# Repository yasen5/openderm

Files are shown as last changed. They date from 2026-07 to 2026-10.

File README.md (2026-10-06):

# OpenDerm

[OpenDerm](https://openderm.github.io/) is an open-source robotic imaging system for creating high-resolution, reproducible 3D maps of the skin that can be compared over time to detect early signs of skin cancer.

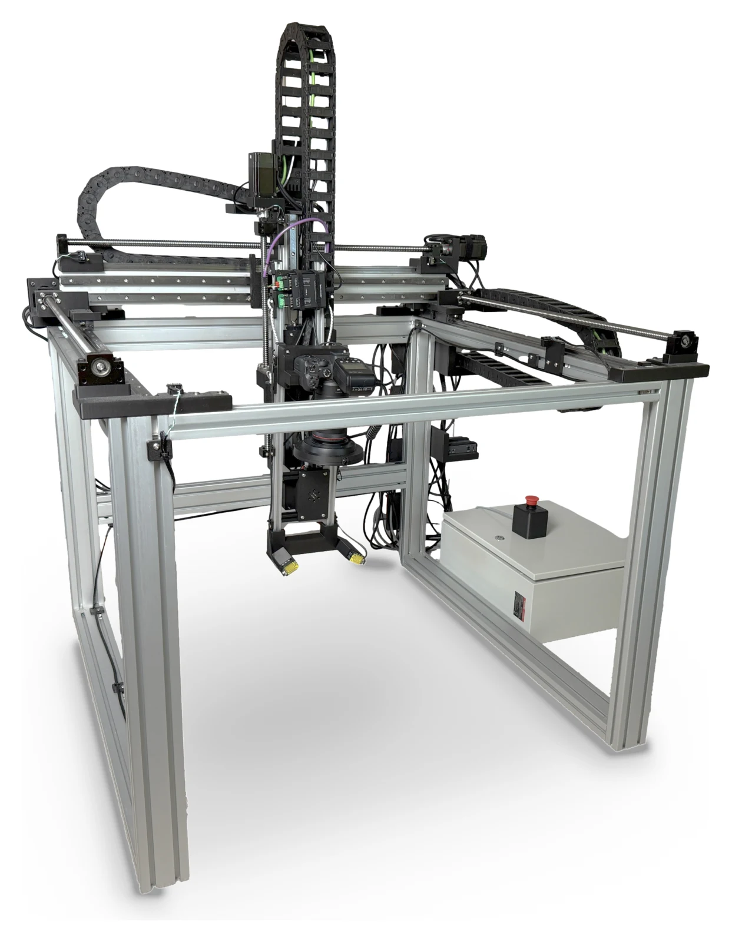
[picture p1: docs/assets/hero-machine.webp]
The OpenDerm four-DOF robotic skin-imaging system


## System architecture

The system uses three computers:

| Computer | Connected hardware | OpenDerm role |
| --- | --- | --- |
| Raspberry Pi #1 (`openderm-gantry.local`) | Octopus Pro/Klipper and the Y/Z Pico | X-axis gantry API and Pico TCP bridge |
| Raspberry Pi #2 | CAN-controlled RX-axis motor, Canon EOS R7, ADS1115, sensor GPIO | Homing, standoff regulation, and scan capture |
| Workstation | | 3D reconstruction, longitudinal comparison |

Raspberry Pi #1 controls the X-axis via Klipper. The Raspberry Pi Pico controls the Y and Z axes; Raspberry Pi #2 controls the RX joint, the camera, and the distance sensors.

## Documentation

### Build and configure

- [Project website](https://openderm.github.io/) — project overview, hardware design, CAD, bill of materials, wiring, and assembly instructions.
- [Raspberry Pi and Octopus Pro setup](docs/fresh-start-pi-octopus-pro.md) — configure Raspberry Pi #1, Klipper, Moonraker, and the X-axis controller.

### Operate and capture

- [Motion control](docs/motion.md) — start the motion services and control the X, Y, Z, and RX axes.
- [Distance sensors and RX limit switches](docs/sensors.md) — sensor wiring, readings, and limit-switch commands.
- [Camera capture](docs/camera.md) — configure Canon EDSDK and capture photographs.
- [Capture and processing procedure](docs/scanning-procedure.md) — preflight, calibration, scanning, reconstruction, and scan comparison.

### Process and compare

- [Skin reconstruction and registration](docs/skin-registration.md) — reconstruction method, longitudinal comparison, uncertainty, and limitations.
- [Simulated capture from freehand photos](docs/sim-capture.md) — build a processing-ready scan with COLMAP when the gantry is unavailable.

### Technical references

- [Self-collision guard](docs/collision_guard.md) — collision-envelope generation, runtime enforcement, and safety behavior.
- [Calibration and collision scripts](docs/calibration-and-collision.md) — RX-pivot calibration, floor calibration, and collision-envelope tools.

## Install

OpenDerm requires Python 3.11 or newer. Clone OpenDerm on both Raspberry Pis and install it into a virtual environment:

```bash
python3.11 -m venv .venv
source .venv/bin/activate
python -m pip install --upgrade pip
python -m pip install -e ".[hardware]"
```

Copy [config/openderm.env.example](config/openderm.env.example) to an untracked local file on both Pis and edit the hostnames or IP addresses. Generate one shared control token, put the same value in both files, and never commit it:

```bash
python -c 'import secrets; print(secrets.token_urlsafe(32))'
```

Load the environment in each shell:

```bash
set -a
source /path/to/openderm.env
set +a
```

If `openderm-gantry.local` does not resolve on Raspberry Pi #2 or an operator workstation, use Raspberry Pi #1's reserved LAN address instead (e.g. 192.168.1.188).

## Start

On Raspberry Pi #1, start the X-axis service and Pico bridge in separate terminals:

```bash
openderm-gantry-server --host 0.0.0.0 --port 8090
openderm-pico-bridge --host 0.0.0.0 --port 8095
```

Non-loopback motion services refuse to start without `OPENDERM_CONTROL_TOKEN`. HTTP clients and the Pico socket client read the token from the environment automatically. Keep ports 8090 and 8095 on a private, firewalled control network; the token does not replace network segmentation or a physical emergency stop.

On Raspberry Pi #2, start the RX-axis service:

```bash
openderm-rx-axis-server --axis rx --host 127.0.0.1 --port 8091
```

## Home and move the robot

Use the `home` and `move-to` commands for every axis:

```bash
openderm --axis x home
openderm --axis x move-to 250 --feed 900

openderm --axis y home
openderm --axis y move-to 175
openderm --axis z home
openderm --axis z move-to 200

openderm --axis rx home
openderm --axis rx move-to 0.95 --speed 0.2
```

The configured linear travel limits are X: 0–800 mm, Y: 0–665 mm, and Z: 0–392 mm. Verify direction, limit switches, and stopping behavior one axis at a time before running a coordinated workflow.

## Regulate standoff

On Raspberry Pi #2, regulate the camera head to the configured 110 mm working distance above the subject:

```bash
openderm-regulate --debug
```

`PICO_PORT` defaults to a TCP bridge derived from `GANTRY_SERVER_URL`. For example, setting `GANTRY_SERVER_URL=http://192.168.1.188:8090` automatically selects `socket://192.168.1.188:8095` unless `PICO_PORT` is set explicitly. Run `openderm-regulate --help` to inspect or adjust the regulation parameters.

## Capture scans

`openderm-scan` follows the subject contour:

```bash
openderm-scan captures/subject-001-site-001 --debug
```

Inspect the resolved capture parameters without moving hardware:

```bash
openderm-scan captures/subject-001-site-001 --show-config
```

Run `openderm-scan captures/subject-001-site-001 --advanced-help` to list the tuning options. Follow the preflight, subject-positioning, focus, overlap, and edge-recovery procedure in [docs/scanning-procedure.md](docs/scanning-procedure.md) before a human scan.

## Reconstruct and compare scans

Install the vision dependencies on a workstation:

```bash
python3.11 -m venv .venv
source .venv/bin/activate
python -m pip install -e ".[vision]"
```

Calibrate the intrinsics of your camera independently with the exact lens, manual-focus setting, and full-resolution image dimensions used for capture. OpenDerm does not provide a camera-calibration utility. The reference camera's full-resolution focal length, `39237 px`, is the default; supply your calibrated focal length with `--fx-full` when it differs:

```bash
openderm-process captures/subject-001-site-001 --fx-full <focal-length-px>
```

`openderm-process` fits the rig model for the current scan, builds the canonical reconstruction, and runs both artifact checks:

```bash
openderm-process captures/subject-001-site-001
```

Use `--quality full` for the sharpest 78 px/mm texture after the preview passes artifact checks.

Compare two canonical scans of the same anatomical site:

```bash
openderm-compare subject-001-site-001 subject-001-site-002 --captures captures
```

Processing outputs include `texture.jpg`, `surface_mesh.obj`, `viewer.html`, `placements3d.json`, `report.txt`, artifact-check crops, and a longitudinal change report. See [docs/skin-registration.md](docs/skin-registration.md) for the reconstruction and uncertainty model.

## Repository layout

- `src/capture/` — hardware control and capture workflows.
- `src/processing/` — 3D registration, artifact detection, and scan comparison.
- `src/sim_capture/` — COLMAP-based stand-in for `src/capture` that builds a scan from freehand photos.
- `src/pico/` — MicroPython Y/Z motion firmware.
- `src/tests/` — hardware-free unit and simulation tests.
- `src/scripts/calibration/` — RX-pivot and floor calibration tools.
- `src/scripts/collision/` — CAD-derived collision-envelope tools.
- `config/` — environment templates, Klipper configuration, CAD models, calibration, and collision tables.
- `third_party/` — vendored Three.js libraries and the Pico compatibility launcher.
- `docs/` — setup, operation, reconstruction, and safety documentation.

Non-code test fixtures belong in `test-assets/` when needed; generated example
outputs are not tracked. Documentation, licenses, and files required at fixed
locations by build tools or GitHub remain outside these directories.

## Verify the installation

```bash
python -m pip install -e ".[hardware,vision]"
python -m pip install pytest
python -m pytest
```

## Safety
> **Caution:** OpenDerm is research software, not a medical device, and does not diagnose melanoma or any other condition. Operating the robot can cause impact, pinch, electrical, and laser hazards; validate limits and emergency stops without a person in the workspace before human imaging.

## License

OpenDerm is available under the [MIT License](LICENSE).

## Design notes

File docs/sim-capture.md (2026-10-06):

# Simulated capture from freehand photos (sim-capture)

`sim-capture` replaces `src/capture` when the gantry is unavailable. It takes a
folder of photographs taken by hand, lets COLMAP estimate where every photo was
taken and the shape of the surface, and writes a capture folder that
`src/processing` reconstructs the same way it reconstructs a gantry scan.

It does not touch `src/capture`, and nothing in `src/capture` is needed to run it.

## What it is and is not

- **Poses are estimated, not measured.** The gantry reports camera position to
  about a millimetre from its encoders. Here the poses come from the images, so
  they are exactly as good as the images allow. Processing still refines them
  with its own bundle adjustment.
- **Scale is not observable from images.** You tell sim-capture the approximate
  mean camera-to-surface distance with `--standoff-mm`, and everything in
  millimetres follows from that number. A 5% error in the standoff is a 5% error
  in every length, including lesion sizes in `openderm-compare`. Do not use
  sim-capture output for clinical measurement.
- **One camera, one zoom.** All images must share a size and focal length. The
  focal length and radial distortion are estimated by COLMAP, not read from a
  calibration.
- **One-sided capture.** Processing models the subject as a heightfield
  `z = f(x, y)` seen from above. Photos should look at the same side of the
  subject with neighbouring views overlapping by about 60%. A full orbit around
  an arm is reported as a warning and will not reconstruct well.
- **No breathing-group handling.** The gantry path registers scan rows
  separately to cancel breathing; freehand captures are registered as one rigid
  group.

## Install

```bash
python -m pip install -e ".[vision,sim]"
```

`pycolmap` provides COLMAP. The CPU build is sufficient; COLMAP's own
`colmap` command is not required.

## Run

```bash
openderm-sim-capture photos/ --out captures/arm-sim-001 --standoff-mm 250
openderm-sim-capture photos/ --out captures/arm-sim-001 --standoff-mm 250 --force --process
```

The first command stops after writing the capture folder and prints the
processing command. `--process` runs it. COLMAP and processing memory grows with
the number and resolution of the images (about 1.5 GB for 24 images at 640x480
during COLMAP in testing), so cap or monitor memory on large sets. COLMAP's SIFT needs about 1 GB per thread at
1440x2560, so `--threads` defaults to 4 (16 threads ran out of memory at 10 GB).

Registration statistics, warnings and the scale factor are in
`captures/arm-sim-001/sim/report.json`. Read it before trusting the result:

| Field | What to look for |
|---|---|
| `images_registered` / `images_unregistered` | Most images should register. Below 50% sim-capture refuses to continue (`--min-registered-frac`). |
| `mean_reprojection_error_px` | Well under 1 px for a good run. |
| `other_models_sizes` | Non-empty means COLMAP found disconnected groups of photos. Only the largest is used. |
| `warnings` | Captures that wrap around the subject, strongly three-dimensional subjects, or very oblique views. |

## Output

```
captures/arm-sim-001/
  <image>.jpg, <image>.json   one pair per registered image (processing's input)
  sim/poses.json              COLMAP poses + intrinsics, read by --poses-from
  sim/report.json             statistics, scale, warnings
  sim/sparse.ply              sparse surface in millimetres
  registration3d/             processing outputs (after --process)
```

The `.json` sidecars follow the gantry schema so the loader accepts them. Their
position fields hold the camera centre and the rotation and distance-sensor fields
hold the surface distance; processing ignores them for pose when `--poses-from`
is given. Every sidecar carries `"sim": true`.

`sim-capture` refuses to write into a folder containing JSON it did not create,
so it cannot mix with a real scan. `--force` replaces only an earlier sim-capture
run.

## Restricting to skin (masks)

Real surroundings (a table, a floor) pull COLMAP's poses, the fitted surface and the
texture toward whatever has the most texture. To use only the subject:

```bash
# 1. one mask per image (needs torch + transformers; Sapiens2 body-part model)
python -m sim_capture.tools.skin_masks photos/ --out masks/
# 2. scale and axes from the masked points; processing restricted to the masks
openderm-sim-capture photos/ --out captures/arm-sim-001 --standoff-mm 150 --skin-masks masks/ --process
```

`skin_masks` merges every body-part class into one skin class, fills small holes,
drops small islands and trims the silhouette edge. It prints the skin share per frame
and flags frames far from the median. Any tool that writes `<image stem>.png`
(255 = subject) works instead.

With `--skin-masks`:

- COLMAP still sees the whole image, because skin alone often has too few features
  and the rigid background constrains the poses well.
- `--standoff-mm` now means camera-to-**skin** distance, and the surface axes come
  from the sparse points that land on skin. sim-capture stops if fewer than 20 do.
- The masks are copied to `sim/masks/` and processing gets `--mask-dir`: keypoints
  and landmarks, so the fitted surface, come from skin only, and the ortho-texture
  paints only skin. This forces the CPU texture renderer.

Check `points_on_mask` in `sim/report.json`; a few hundred is typical.

## Using video

```bash
python -m sim_capture.tools.frames_from_video clip.mp4 --out photos --max-frames 90 --max-width 1920
```

samples the video, then keeps the sharpest frame in each time bin so motion blur
does not reach COLMAP. Use footage with a slow, continuous camera move, no cuts or
zoom, and no electronic stabilization crop.

## What changed in src/processing

`register_scan_3d --poses-from sim/poses.json` is a new opt-in mode. When it is
not given, processing behaves as before.

- Camera poses and intrinsics come from the file instead of the gantry rig model.
  The rig pre-fit and the consecutive/cross-row matching are skipped.
- `--mask-dir DIR` (optional) restricts keypoints and texture to per-frame masks
  `<image stem>.png`. Every frame needs one.
- Candidate image pairs still come from predicted footprint overlap. Matches are
  verified against the epipolar geometry of the supplied poses
  (`verify_pair_with_known_poses`), not with the similarity-transform RANSAC,
  which assumes nearly frontal views and little perspective change.
- The gantry-specific bundle-adjustment heuristics (the narrow-field valley
  re-split and its fixed sigmas) are bypassed. `--sigma-t`, `--sigma-r` and
  `--fx-full 0` still apply.
- `placements3d.json` gains `pose_source` (`"gantry"` or `"external"`). With
  `"external"`, the rig fields `lever_mm`, `Rm`, `rx_sign` and `dz0_mm` are
  placeholders and each frame's `R_cam2world` and `C_mm` are authoritative.

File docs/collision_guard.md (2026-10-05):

# Self-collision guard — design

Config-dependent self-collision avoidance for the 4-DOF gantry (x, y, z, rx). A safe `(x, y)` envelope that varies with `(rx, z)` is derived from the CAD model, allowing the machine to use the portion of its travel that is collision-free.

## Pipeline (offline → runtime)

1. **CAD → URDF** (`config/cad/robot.urdf`, generated with `onshape-to-robot`).
2. **Collision engine** (`src/scripts/collision/collision_model.py`; install with `pip install -e ".[collision]"`): clearance between every moving link and the static frame or other non-adjacent links, using the real→CAD calibration (`config/cad/frame_calibration.json`). ACM = adjacent (carriage-on-rail) + structural overlaps from known-safe poses.
3. **Envelope sweep** (`src/scripts/collision/build_collision_envelope.py`): raw min-clearance grid over `(rx, z, x, y)` in real controller units → `config/cad/collision_clearance.npz`. Travel ranges come from `config/cad/frame_calibration.json`; margin, backlash, and grid resolution come from `config/scripts.json`. `derive` re-thresholds the selected `--grid` at the configured margin + rx-backlash (rx interpolated fine) → safe masks + robust-clearance grid at the required `--out` path. Reference configuration: **20 mm margin, ±2.5°**. See [utility commands](calibration-and-collision.md).
4. **Runtime guard** (`src/capture/motion/collision_guard.py`, numpy-only, control host): loads the envelope, answers `is_safe / min_clearance / check_pose / check_path`. **Never calls FCL at runtime** — pure table lookup.

## The architectural constraint

X (Klipper/Moonraker through the gantry server on port 8090), Y/Z (Pico through the serial bridge on port 8095), and RX (RX-axis server on port 8091) are **separate controllers with no shared state or atomic full-pose command**. The complete `(x, y, z, rx)` target exists **in the scan control loop**, where `move_regulated_pose()` computes the x/y pivot arc, finalizes z, and holds `rx_target` before dispatch. The **primary, authoritative check lives in the loop**, using the *commanded target* pose.

## Decisions

- **On violation: reject discrete moves, hold streamed moves.** A discrete `move_xyz` that would enter an unsafe pose raises `GantryCollisionError`; a streamed regulation setpoint that would cross the boundary holds at the last safe setpoint (does not advance).
- The scan controller enforces the complete four-axis pose. Manual motion must still be performed conservatively because separate axis services do not share an atomic four-axis state.
- The collision envelope governs frame clearance. The physical axis travel limits enforced by the X server and Pico firmware remain independent safety boundaries.

## Runtime guard API (`collision_guard.py`, numpy-only)

- `min_clearance(x, y, z, rx) -> float` — **conservative** lookup: min robust-clearance over the grid hypercube surrounding the query (fail-safe against the coarse grid); queries outside the swept ranges return `-inf` (fail closed). rx is already ±2.5° backlash-padded in the envelope, so the commanded rx is used directly.
- `is_safe(x, y, z, rx) -> bool` — `min_clearance >= margin`.
- `check_pose(x, y, z, rx)` — raises `GantryCollisionError` if unsafe (discrete-move use).
- `check_path(a, b, n)` — samples n interpolated poses A→B; also samples the **rx-leads-xyz** transient corner (rx is dispatched fire-and-forget before x/y/z), so a path whose endpoints are safe but whose transit isn't is rejected.
- Margin is a **runtime config** applied to the robust-clearance grid at load, so it is retunable without regenerating the envelope. Regenerate and independently validate the envelope after any CAD, calibration, or mechanical change.

## Enforcement

In `capture.scanning.contour`:

- **Startup gate**: perform a full-pose safety check on the current parked pose; abort the scan if already unsafe.
- **Per-move**: call `check_pose(x, y, z, rx_target)` after assembling the full target and before dispatch. On `GantryCollisionError`, skip the move and flag the station edge as collision-limited.
- **Path**: `check_path(previous_commanded_pose, target)` so transit is safe too.
- **Streamed mode**: hold the setpoint at the last safe pose instead of advancing.

## Rollout / validation

**Enforced by default.** `OPENDERM_COLLISION_MODE=off` only *disables* the guard (e.g. bench work without hardware) — there is deliberately **no "shadow"/log-only mode**: a safety limit that prints but doesn't stop gives a false sense of protection and cannot be relied upon. Commission the physical limits and collision envelope with an independent engineering safety procedure before human use. Edit the collision margin in `config/scripts.json`, then run `build_collision_envelope.py derive --grid config/cad/collision_clearance.npz --out config/cad/collision_envelope.npz` to update the envelope without a new sweep. An over-conservative margin may stop a scan early; do not reduce it solely because the software model reports clearance.

## Caveats

- Use **commanded** targets, not live `/state` reads, for the loop check (gantry `/state` is extrapolated mid-move).
- rx readback is firmware-belief, not true camera angle (backlash downstream of the encoder). The ±2.5° envelope padding + commanded rx cover this; widen if backlash grows.
- Don't mask silent move failures (blocking `/move` can return 200 with `status='failed'`).
- Envelope fidelity == CAD + calibration fidelity; regenerate on any CAD/calibration change.

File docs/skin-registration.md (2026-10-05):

# Skin scan registration — goal & method

## Goal

Build 2D skin maps for **(a)** reviewing fine surface features and **(b)** researching how those features can be tracked across scans taken on different days. The output is not a diagnosis and requires clinician review. The subject can move or **breathe** during the minutes-long scan, so the reconstruction must tolerate small between-pass changes.

The diagnostic signal is the **2D skin texture**, not 3D shape. So the 3D surface is only a **scaffold** to unwrap onto — it must be **smooth, stable, and reproducible**, not an accurate instantaneous reconstruction. This makes breathing a *nuisance to reject*, not motion to reconstruct.

## Key Components

1. **Lock fx.** The narrow ~8° FOV makes focal length and depth nearly degenerate. Calibrate the camera intrinsics independently with the exact capture configuration, then pass the full-resolution focal length in pixels through `--fx-full`. OpenDerm defaults to `39237 px` for the reference camera.
2. **Lock manual focus at capture.** Autofocus changes magnification ~1%/frame at macro distance (focus position *is* effective focal length).
3. **Use each measurement for what it observes.** Images provide sub-pixel *in-plane* precision while the recorded robot poses and surface landmarks provide the reconstruction scaffold.
4. **Fit the subject contour** (`--contour on`). The landmark surface follows the captured anatomy without relying on a camera-frame laser calibration.
5. **Deformable in-plane alignment, keeping the scaffold stable** (`--deformable`). A smooth per-frame affine warp *in the 2D map* aligns overlapping frames' features, removing the residual breathing offset so stitch seams don't cross moles. The 3D surface is left untouched — only texture content is aligned.
6. **Gantry-anchored unwrap.** Parameterize the map in the gantry (proprioception) frame so the same skin lands at the same map coordinate every scan — the precondition for cross-time comparison. Subject repositioning between days is handled later, by feature matching across scans.
7. **Two-band blend.** HF detail is winner-take-all per texel (sharp, single-source — no ghosting); LF illumination is feather-blended (smooth — no per-frame tiling); a small floor on the centre weight guarantees no coverage gaps. `--blend two-band --focus-weight 4`.

## Calibration

- **fx = 39237 px by default.** This value applies to the reference camera. Calibrate your own camera externally and override it with `--fx-full`. Recalibrate if the camera, lens, focus, or image dimensions change.
- **Surface model.** Reconstruction uses the per-scan landmark contour, avoiding camera-frame geometry that could become invalid after a mechanical change.

## Recommended commands

```bash
openderm-process captures/<scan>
```

The command first fits the current scan's rig model without `--rig-from`, then uses that scan's own stage-one `placements3d.json` for the canonical run. Preview quality uses `--downscale 3 --texture-ppmm 20`; add `--quality full` for `--downscale 1 --texture-ppmm 78`. The wrapper also runs the doubling and ghost checks.

## Cross-time tracking

Run both scans as above and they land in the **same gantry-anchored frame**. Compare by detecting moles in each map and matching them (the moles are their own fiducials); the residual after aligning the stable moles is the change signal.

**Tool: `openderm-compare SCAN_A SCAN_B`.** Reads each scan's `registration3d-canonical/` and:

1. **Common canvas** — recovers each map's `(u,v)`-mm gauge (`tex_anchor.py`) and resamples both onto one common `(u,v)` canvas at 20 px/mm; intersects the coverage masks to the region imaged in **both** scans. The texture is linear in `(u_mm, v_arclen_mm)`, so only each scan's `(umin,vmin)` offset is needed.
2. **Melanin + flatten** — `M = -log(R)` high-passed by a ≥12 mm background estimated from covered skin only, making the detector robust to residual session-wide exposure differences.
3. **Tiered alignment** — SIFT+RANSAC similarity, **accepted only if near-identity** (the shared gantry gauge guarantees the residual transform is ~identity; a scale-0/180°/clumped fit is rejected). Falls back to a **mole-constellation** fit (moles as fiducials), then to **gantry-only** (low confidence).
4. **Mole detection** — multiscale-LoG on the melanin map over physical scales, kept by a melanin-contrast threshold; NMS by blob radius.
5. **Match + verdict** — NN under the alignment-residual prior with a constellation cross-check; NEW / DISAPPEARED **hard-gated to mutual coverage**. Verdict tier: RELIABLE / PROVISIONAL / LOW-CONFIDENCE.

Outputs to `captures/<A>/compare-<B>/`: `change_report.json` + `.csv`, `change_overlay.png` (green=stable, red=new, blue=disappeared, dim=outside mutual coverage), `detections_{A,B}.jpg`, `common_{A,B}.jpg`.

Each reconstruction records the exact texture gauge in the `texture` block of `placements3d.json` and writes a lossless `coverage.png`. Comparison requires both artifacts and will ask the user to rebuild an incomplete reconstruction.

Use same-scan null tests to verify that all lesions match with no false new or disappeared detections. Cross-visit comparisons require generous overlap and enough stable fiducials to estimate repositioning; otherwise the tool should report low confidence and abstain.

### Lesion size-change and uncertainty

`src/processing/track_moles.py` (wired into `compare_scans`, stage `[6]`). For every matched mole pair it reports Δdiameter, Δarea, Δshape with a per-mole error bar and a significance flag (grew / shrank / stable).

- **Exposure-invariant size.** `melanin_flat` is a log-ratio (`log(R_skin/R)`), so a multiplicative exposure/WB gain cancels — size is measured at the **half-max iso-contour of each mole's own peak** (a fraction-of-peak boundary), not an absolute threshold. Saturated or badly exposed images are rejected during capture review because destroyed image information cannot be recovered.
- **Warp-independent measurement.** Every size number is measured in each scan's **own un-warped frame**; the transform is used only to MATCH moles, never to resample lesion pixels, so alignment cannot erase an apparent size change.
- **Uncertainty** = registration σ (local residual of the chosen transform's inliers, interpolated to the mole — RBF for dense SIFT, IDW for sparse moles) ⊕ detector σ (std over jittered re-detections, using the scan's own skin noise) ⊕ a null floor, in quadrature. **Significant** iff |z|≥k AND |Δ|≥floor. Conservative defaults are k=2.5 and a 0.30 mm floor. Use same-scan null comparisons to characterize the complete system before interpreting results.
- **Outputs:** `change_report.json/.csv` (per mole: d_eq_a/b, Δ±σ, z, class, significant), `change_overlay.png` (moles colored stable/grew/shrank/new/gone), `change_montage.png` (per-mole baseline|follow-up crops with the measured contour).

## Pitfalls already fixed (don't reintroduce)

- **Coverage gaps** from a too-peaked centre weight → small floor on the centre weight in the renderer.
- **Illumination tiling** from blending the LF band with the peaked weight → blend the LF with the gentle feather-only weight; keep HF winner-take-all.
- **Holes over featureless skin** from gating the surface support on SIFT-feature density → the support is filled (the surface is laser-driven, not feature-gated).

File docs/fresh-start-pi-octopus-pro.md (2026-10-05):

# Fresh Start: Raspberry Pi 5 + Octopus Pro V1.1

This guide assumes the Raspberry Pi 5, the BigTreeTech Octopus Pro V1.1, and the X-axis CL57Y driver are all new and unconfigured. The Pi runs Klipper host services and Moonraker, while the Octopus Pro generates real-time step pulses for X only. Y and Z are connected to the Pico described in the root README.

## 1. Gather parts

You need:

- Raspberry Pi 5 with power supply, microSD card, and network access
- Octopus Pro V1.1
- USB cable from Pi to Octopus
- 24V or other appropriate board power supply for the Octopus
- CL57Y driver, NEMA 23 motor, and motor power supply
- Two Omron SS-5GL2 limit switches
- Small screwdriver, multimeter, and ferrules or crimped wire ends

Do the first software steps with the Pi and Octopus only. Leave the motor disconnected until Klipper can see endstops correctly.

## 2. Prepare the Raspberry Pi

Recommended path: flash `MainsailOS` to the Pi. 

1. Install Raspberry Pi Imager on your computer.
2. In the imager, choose `MainsailOS` for Raspberry Pi.
3. Open the imager's advanced options before writing the card.
4. Set:
   - hostname, for example `openderm-gantry`
   - a username and password
   - your Wi-Fi SSID and password if not using Ethernet
   - locale and timezone
   - SSH enabled
5. Write the image to the microSD card.
6. Insert the card into the Pi, connect network, then power it on.
7. Wait a few minutes for first boot and filesystem expansion.

After boot, connect by SSH:

```bash
ssh <pi-user>@openderm-gantry.local
```

Then update packages:

```bash
sudo apt update
sudo apt full-upgrade -y
sudo reboot
```

## 3. Setup the Octopus Pro

Before applying board power:

1. Confirm the board is actually `Octopus Pro V1.1`.
2. Read the voltage-jumper warning in the BTT manual. The board supports both `MOTOR_POWER` and `Main Power`, and using the wrong side can damage drivers.
3. Because you are using an external CL57Y driver, you do not need to install a plug-in stepper driver on the Octopus for this axis.
4. For first bring-up, connect only:
   - Octopus board power
   - USB from Pi to Octopus
   - one home switch
   - optionally the far-end switch
5. Leave the motor phases and high-current motor supply disconnected until endstops and step/dir polarity are confirmed.

## 4. Wire the axis as a simple step/dir system

For this repo, treat one Octopus stepper socket as a signal source only.

- Octopus `STEP` -> CL57Y `PUL`
- Octopus `DIR` -> CL57Y `DIR`
- Octopus `EN` -> CL57Y `ENA` if you want software enable control
- Octopus signal ground -> CL57Y logic ground
- Home switch -> the configured `X` endstop input
- Far-end limit switch -> a spare input used for emergency stop

The baseline config in this repo assumes:

- `stepper_x.step_pin = PF13`
- `stepper_x.dir_pin = PF12`
- `stepper_x.enable_pin = PF14`
- `stepper_x.endstop_pin = ^PG6`
- far-end limit on `PG9`

Those values come from Klipper's generic Octopus Pro v1.1 pin mapping and this repo's starter config. Verify them against your exact wiring before continuing.

## 5. Flash Klipper to the Octopus Pro

SSH into the Pi and find the Klipper source. On MainsailOS it is typically already installed in `~/klipper`. If it is missing, install Klipper through Mainsail/KIAUH first.

Build firmware:

```bash
cd ~/klipper
make menuconfig
```

Use these settings for the common Octopus Pro V1.1 STM32H723 build:

- enable low-level configuration options
- micro-controller: `STM32H723`
- bootloader offset: `128KiB bootloader`
- clock reference: `25 MHz crystal`
- communication interface: `USB (on PA11/PA12)`

Then compile:

```bash
make
```

Flash using the method supported by your board revision. The common SD-card method is:

1. Copy `out/klipper.bin` to a microSD card as `firmware.bin`.
2. Power the Octopus off.
3. Insert the card.
4. Power the Octopus on.
5. Wait for the flash to complete.
6. Check whether the file was renamed to `FIRMWARE.CUR` or similar. That usually indicates a successful flash.

After flashing, reconnect USB to the Pi and find the board's serial path:

```bash
ls /dev/serial/by-id/*
```

## 6. Install this repo's Klipper config

Clone this repository on the Pi if you have not already:

```bash
cd ~
git clone <your-repo-url> openderm
cd ~/openderm
```

Copy the baseline Klipper files into the active config directory:

```bash
mkdir -p ~/printer_data/config
cp config/klipper/printer.cfg ~/printer_data/config/printer.cfg
cp config/klipper/macros.cfg ~/printer_data/config/macros.cfg
```

Edit `~/printer_data/config/printer.cfg` and set:

- the exact `serial:` path from `ls /dev/serial/by-id/*`
- correct endstop pins if your wiring differs
- `position_max` to your usable travel
- `rotation_distance` if your mechanics require a different conversion

For the RM1605 ballscrew, `rotation_distance: 5`.

Restart Klipper from the Mainsail web UI or with:

```bash
sudo systemctl restart klipper
sudo systemctl restart moonraker
```

## 7. Verify board communication before connecting the motor

Open the Mainsail web UI in a browser. The hostname is usually your Pi hostname with `.local`, for example:

```text
http://openderm-gantry.local
```

In the console:

1. Run `STATUS`. Klipper should report ready.
2. Run `QUERY_ENDSTOPS`.
3. Trigger the home switch by hand and run `QUERY_ENDSTOPS` again.
4. Confirm the switch state changes correctly.

If the logic is reversed, invert the pin in `printer.cfg`, for example `PG6` to `!PG6` or `^PG6` to `^!PG6`, then save and restart.

Do not attempt homing until both switch polarity and travel direction make sense.

## 8. Connect and validate the CL57Y and motor

With board communication working:

1. Power everything off.
2. Wire the CL57Y to the motor exactly per its manual.
3. Wire the CL57Y logic inputs to the Octopus pins chosen in `printer.cfg`.
4. Set the CL57Y current and microstep switches conservatively for the first run.
5. Power the driver and board back on.

Before issuing a real move:

1. Keep the axis mechanically clear.
2. Confirm the ballscrew can rotate freely.
3. Be ready to cut power.

From Mainsail, send a tiny move:

```text
G91
G1 X5 F300
G90
```

If direction is wrong, invert `dir_pin` by adding or removing `!`.

If motion scale is wrong, re-check:

- `rotation_distance`
- CL57Y microstep switch settings
- whether the motor is really 200 full steps per revolution

## 9. Set up safe homing

After manual jogging works:

1. Move the carriage near the middle of the axis.
2. Run `QUERY_ENDSTOPS` one last time.
3. Issue `G28 X`.
4. Confirm the carriage moves toward the home switch.
5. Confirm it stops when the switch triggers, retracts, and re-homes slowly.

If the carriage moves away from home, stop immediately and fix `dir_pin`.

If the carriage hits the switch and keeps pushing, stop immediately and fix `endstop_pin` polarity.

## 10. Install the Pi-side control client from this repo

From the repository root on the Pi:

```bash
cd ~/openderm
python3 -m pip install -e ".[hardware]"
```

If Moonraker uses a non-default local address, set it before starting the X-axis service:

```bash
export MOONRAKER_WS_URL=ws://127.0.0.1:7125/websocket
export OPENDERM_CONTROL_TOKEN="replace-with-the-same-random-token-used-on-pi-2"
openderm-gantry-server --host 0.0.0.0 --port 8090
```

The gantry server refuses a non-loopback bind without the shared token. Keep
port 8090 restricted to the private control network.

In another shell, verify status before homing and moving X:

```bash
openderm --axis x status
openderm --axis x home
openderm --axis x move-to 250 --feed 900
openderm --axis x move-by -10 --feed 900
```

Klipper controls X only. Follow the root README to install
`src/pico/gantry_firmware.py` as `main.py` and start `openderm-pico-bridge` for Y/Z
control.

## 11. Calibrate before use

Before treating the axis as production-ready:

1. Measure actual travel over a commanded move and fine-tune `rotation_distance`.
2. Set conservative `max_velocity` and `max_accel`.
3. Test both limit switches.
4. Verify emergency stop behavior.
5. Confirm the carriage cannot crash into either end due to soft-limit errors.

## References

- Raspberry Pi Imager: <https://www.raspberrypi.com/software/>
- Klipper installation guide: <https://www.klipper3d.org/Installation.html>
- Moonraker installation guide: <https://moonraker.readthedocs.io/en/latest/installation/>
- MainsailOS docs: <https://docs.mainsail.xyz/mainsailos/>
- Klipper generic Octopus Pro v1.1 config: <https://raw.githubusercontent.com/Klipper3d/klipper/master/config/generic-bigtreetech-octopus-pro-v1.1.cfg>
- BigTreeTech Octopus Pro repo: <https://github.com/bigtreetech/BIGTREETECH-OCTOPUS-Pro>

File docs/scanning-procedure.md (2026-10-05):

# Capture and processing procedure

## 1. Prepare the system

Confirm all of the following with an inert target first:

- The emergency stop removes motion power and is reachable by the operator.
- X, Y, Z, and RX limit switches report correctly.
- X travel is limited to 0–800 mm, Y to 0–665 mm, and Z to 0–392 mm.
- Klipper owns X only. The Pico exclusively owns Y and Z.
- The collision model is enabled (`OPENDERM_COLLISION_MODE=enforce`).
- Both Pis have the same untracked `OPENDERM_CONTROL_TOKEN`, and motion ports
  are restricted to the private control network.
- The Canon lens is manually focused at the 110 mm working distance, and image stabilization is off.

Start Pi #1:

```bash
openderm-gantry-server --host 0.0.0.0 --port 8090
openderm-pico-bridge --host 0.0.0.0 --port 8095
```

Start the RX service on Pi #2:

```bash
openderm-rx-axis-server --axis rx --host 127.0.0.1 --port 8091
```

## 2. Calibration prerequisites

Calibrate your camera intrinsics independently using the exact camera, lens, manual-focus setting, and full-resolution image dimensions used for capture. OpenDerm does not provide a camera-calibration utility. Pass the calibrated full-resolution focal length in pixels to `openderm-process` with `--fx-full`. The default is `39237 px`, which applies to the reference camera configuration. Recalibrate after changing the camera, lens, focus, or image dimensions.

`openderm-process` fits the rig model for every scan and then uses that scan's own stage-one placements. Do not reuse placements from another scan or from a different mechanical configuration.

The RX pivot model used during capture must also match the current lever arm. With an inert target, record at least six same-point poses across the intended RX range, then fit the model:

```bash
python src/scripts/calibration/rx_pivot_capture.py 0.95 \
    --record-file captures/rx_pivot_poses.jsonl
python src/scripts/calibration/rx_pivot_fit.py captures/rx_pivot_poses.jsonl \
    --out captures/rx_pivot_model.json
```

Configure the rig's connections, regulation settings, and homing policy in `config/scripts.json` before calibration. Capture angles are radians unless `rx_pivot_capture.degrees` is set to `true` in that file. The capture utility regulates Z while the arrow keys make small X/Y alignment jogs. Press Enter to record a pose and enter the next RX angle. The example explicitly writes `captures/rx_pivot_model.json`, which is the scanner default. See [calibration and collision scripts](calibration-and-collision.md) for the other utility commands.

## 3. Home and position

Home one axis at a time while watching the motion direction:

```bash
openderm --axis x home
openderm --axis y home
openderm --axis z home
openderm --axis rx home
```

Move to a conservative pose above the inert target, then use explicit `move-to` commands to approach the planned start point. Never copy a start pose from another physical build without checking clearances.

```bash
openderm --axis x move-to <x-mm>
openderm --axis y move-to <y-mm>
openderm --axis z move-to <z-mm>
openderm --axis rx move-to <rx-rad> --speed 0.2
```

Keep Y inside the scan window 50–570 mm. The subject surface must already be within sensor range at the start point.

## 4. Verify standoff regulation

With an inert target, run:

```bash
openderm-regulate --debug
```

The average sensor distance should converge to 110 mm and `sensor1-sensor2` should converge toward zero.

The regulator defaults are:

```text
--target-mm 110 --rx-gain-rad-per-mm -0.005 --rx-max-step-rad 0.004
--rx-filter-alpha 0.2 --samples 1 --rx-speed-rad-s 0.02
--rx-deadband-mm 0.5
```

Press Ctrl-C after stable regulation. Verify the final position before capture.

## 5. Capture a scan

Place X along the primary scan direction. The scanner follows the subject surface in Y and tilts RX around its contour. Run a short `--no-camera` test first:

```bash
openderm-scan captures/test-scan-motion --no-camera --x-travel-mm 40 --debug
```

Confirm that edge recovery tilts toward the body, all pivots remain clear, and the scan parks safely. Then capture:

```bash
openderm-scan captures/<subject-id>-<site>-<session> --debug
```

The default scan uses 300 mm X travel, 20 mm X spacing, 15 mm Y spacing, continuous Pico motion, 110 mm standoff, Z 5–392 mm, floor rejection at 507±3 mm, edge recovery, RX velocity control, and motion tracing. Run `--show-config` to see every expanded setting.

For a different rig, floor, or field of view, treat those numbers as a starting profile—not universal geometry. Re-measure floor depth before human imaging.

## 6. Inspect the raw capture

Confirm that every entry in `poses.jsonl` has its expected JPEG and CR3 image. 

## 7. Reconstruct

Build a preview reconstruction:

```bash
openderm-process captures/<scan>
```

The command runs two stages. Stage one fits the current scan's rig model without `--rig-from` and writes `registration3d-rigfit/placements3d.json`. Stage two uses exactly that file and writes `registration3d-canonical/`. It then runs the doubling and projection-ghost artifact checks.

Drive confirmed doubling and ghost counts to zero. At full 78 px/mm, small freckle self-similarity can create false positives; inspect every reported crop. After a clean preview, run:

```bash
openderm-process captures/<scan> --quality full
```

## 8. Compare visits

Both scans must cover the same site with an in-frame fiducial and generous overlap. Register them independently with `openderm-process`, then run:

```bash
openderm-compare <baseline-scan> <follow-up-scan> --captures captures
```

Review mutual coverage, alignment confidence, residuals, and uncertainty before reviewing any lesion-change classification. Low-confidence or non-overlapping results are abstentions, not evidence of no change.

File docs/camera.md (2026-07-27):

# Camera

## Canon EOS R7 USB Capture

The camera attached to the end-effector is a Canon EOS R7 with a Canon RF100mm F2.8 L Macro lens.

Canon's support pages list the EOS R7 as supporting the official `EDSDK` over USB, and the EOS R7 support page exposes `Linux ARM` as a supported OS family. This repo includes a still-capture CLI for that path:

```bash
pip install -e ".[hardware]"
openderm-canon-capture --output-dir captures --count 1
openderm-canon-capture --output-dir captures --count 5 --interval-s 1.5
openderm-canon-capture --edsdk-lib /opt/canon/edsdk/libEDSDK.so
```

Notes:

- Download the Canon Linux ARM EDSDK separately from Canon and install libEDSDK.so on the Pi.
- The code sets the camera save target to the host and downloads the image when Canon raises the transfer event.
- A capture timeout usually means the camera is not in a remote-control-ready state over USB or the EDSDK library is missing.

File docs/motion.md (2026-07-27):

# Motion

OpenDerm has four controlled degrees of freedom:

- X is controlled by Klipper through `openderm-gantry-server` on Raspberry Pi #1.
- Y and Z are controlled by the Raspberry Pi Pico through `openderm-pico-bridge` on Raspberry Pi #1.
- RX is controlled through `openderm-rx-axis-server` on Raspberry Pi #2.

The Klipper service controls X only. OpenDerm always sends Y and Z commands to the Pico.

## Services

Create one random control token, store the same value in the untracked
OpenDerm environment file on both Pis, and load that file before starting
services or clients:

```bash
python -c 'import secrets; print(secrets.token_urlsafe(32))'
export OPENDERM_CONTROL_TOKEN="replace-with-the-generated-token"
```

Start the X-axis command server and Pico bridge on Raspberry Pi #1:

```bash
openderm-gantry-server --host 0.0.0.0 --port 8090
openderm-pico-bridge --host 0.0.0.0 --port 8095
```

Start the RX command server on Raspberry Pi #2:

```bash
openderm-rx-axis-server --axis rx --host 127.0.0.1 --port 8091
```

Set the service addresses on Raspberry Pi #2 and in operator shells:

```bash
export GANTRY_SERVER_URL=http://openderm-gantry.local:8090
export PICO_PORT=socket://openderm-gantry.local:8095
export RX_AXIS_SERVER_URL=http://127.0.0.1:8091
```

Motion services bind to loopback by default. A non-loopback bind is rejected
unless `OPENDERM_CONTROL_TOKEN` is set. HTTP clients add it as a bearer token,
and the Pico socket client authenticates before serial bytes are relayed.
Restrict ports 8090 and 8095 to a private, firewalled control network as well.

## Operator commands

Home each axis before commanding motion:

```bash
openderm --axis x home
openderm --axis y home
openderm --axis z home
openderm --axis rx home
```

Move to absolute positions:

```bash
openderm --axis x move-to 250 --feed 900
openderm --axis y move-to 175 --feed 900
openderm --axis z move-to 200 --feed 900
openderm --axis rx move-to 0.95 --speed 0.2
```

Relative moves, status, and stops use the same axis selection:

```bash
openderm --axis y move-by -10 --feed 900
openderm --axis rx status
openderm --axis rx stop
openderm --axis rx clear-errors
```

When `--axis` is omitted, `openderm` controls X.

## X-axis command server

`openderm-gantry-server` maintains the Moonraker WebSocket connection, serializes X commands, enforces the 0–800 mm travel range, and supports the streamed X setpoints used during scanning.

The primary HTTP endpoints are:

```text
GET  /healthz
GET  /state
POST /move
POST /home
POST /stop
POST /stream/start
POST /stream/target
POST /stream/stop
```

`POST /stop` is an out-of-band, latched emergency stop by default: it calls
Moonraker immediately instead of waiting behind an active move. Recovery
requires `POST /reset` followed by homing. Callers that only intend to cancel
queued and streamed commands may explicitly request `{"mode": "soft"}`; a
soft stop does not interrupt G-code already executing in Klipper.

The server reads `MOONRAKER_WS_URL`, which defaults to `ws://localhost:7125/websocket`.

## Pico bridge

`openderm-pico-bridge` exposes the Pico serial protocol over an authenticated
TCP connection so Raspberry Pi #2 can control Y and Z through one shared
connection. The Pico firmware performs homing, real-time motion generation,
and physical-travel limit enforcement for both axes.

The default serial device is `/dev/ttyACM0`. Override it when necessary:

```bash
openderm-pico-bridge --serial /dev/ttyACM1 --host 0.0.0.0 --port 8095
```

## RX command server

`openderm-rx-axis-server` owns the SocketCAN connection, reads motor feedback, homes RX against its limit switch, enforces its verified position and speed ranges, and stops the motor when a limit switch, current limit, temperature limit, or velocity dead-man guard trips.

The primary HTTP endpoints are:

```text
GET  /healthz
GET  /state
GET  /limit-switches
POST /poll
POST /home
POST /move-to
POST /velocity
POST /stop
POST /clear-errors
```

The default CAN interface is `can1`. Override it with `GANTRY_RX_CAN_INTERFACE`.

Configure SocketCAN before starting the server:

```bash
sudo ip link set can1 down
sudo ip link set can1 type can bitrate 1000000
sudo ip link set can1 up
```

The RX server rejects motion until homing succeeds. A safety shutdown remains latched until the cause is corrected and `openderm --axis rx clear-errors` succeeds.

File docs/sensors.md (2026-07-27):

# Sensors

## HG-C Sensor Control

The `openderm-sensors` command controls and reads the two HG-C1100-P sensors on Raspberry Pi #2.

Default wiring assumptions:

```text
sensor1 -> ADS1115 A2, GPIO 5
sensor2 -> ADS1115 A1, GPIO 6
ADS1115 I2C address -> 0x48
I2C bus -> /dev/i2c-1
```

Example commands:

```bash
# enable only sensor1 (A2 / GPIO 5)
openderm-sensors enable --sensor sensor1

# disable only sensor1 again
openderm-sensors disable --sensor sensor1

# enable all configured sensors, take one averaged reading, then disable them again
openderm-sensors read --sensor all

# read only sensor2 and average 10 ADC samples
openderm-sensors read --sensor sensor2 --samples 10

# keep sensor1 enabled and continuously print JSON readings until Ctrl-C
openderm-sensors watch --sensor sensor1 --interval-s 0.25
```

Each reading reports:

- measured analog voltage from the ADS1115
- inferred loop current in mA using the configured shunt resistor
- converted distance in mm
- distance offset from the configured center point
- whether the sensor output is inside the configured 4-20 mA range

The HG-C1100-P sensors are assumed to be wired in current-output mode. The code reads the ADS1115 voltage across a shunt resistor, converts that to loop current, then linearly maps `4-20 mA` to `65-135 mm`.

Default calibration:

```bash
export HG_C_SHUNT_RESISTANCE_OHMS=150
export HG_C_CURRENT_MIN_MA=4
export HG_C_CURRENT_MAX_MA=20
export HG_C_DISTANCE_MIN_MM=65
export HG_C_DISTANCE_MAX_MM=135
export HG_C_SENSOR_1_ADC_CHANNEL=2
export HG_C_SENSOR_1_GPIO_PIN=5
export HG_C_SENSOR_ENABLE_ACTIVE_HIGH=0
export HG_C_I2C_BUS_NUMBER=1
```

The ADS1115 code prefers the Adafruit/Blinka stack when it works, and falls back to direct Linux I2C access through `smbus2`.

For sensor enable GPIO pins, the code prefers `gpiozero` when its backend works on the target Pi, and falls back to the Linux `gpiod` Python package.

## RX Limit Switches

The `openderm-limit-switches` command prints when either RX limit switch is pressed.

Defaults assume BCM GPIO numbering and normally-open switches wired from GPIO to ground:

```text
RX left limit switch: GPIO 26
RX right limit switch: GPIO 16
Input mode: pull-up, pressed when shorted to ground
```

Run:

```bash
openderm-limit-switches
```

Use `--active-high` for pull-down wiring, or override pins with `--rx-left-pin` and `--rx-right-pin`. The watcher uses Linux `gpiod` first, with `gpiozero` as a fallback.

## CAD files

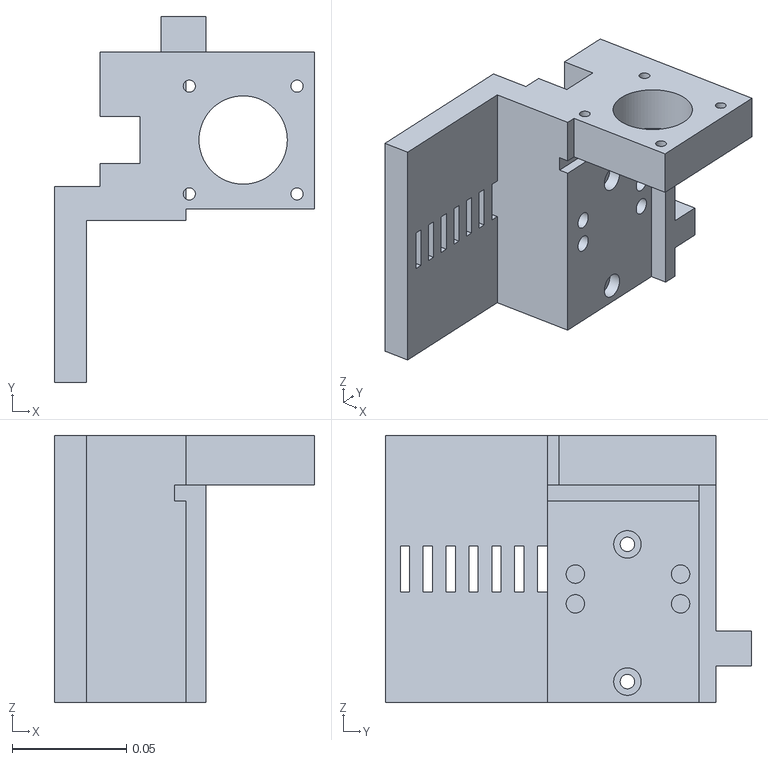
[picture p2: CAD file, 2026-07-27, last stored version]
cad/assets/part_1__20.stl
0.114 x 0.16 x 0.117

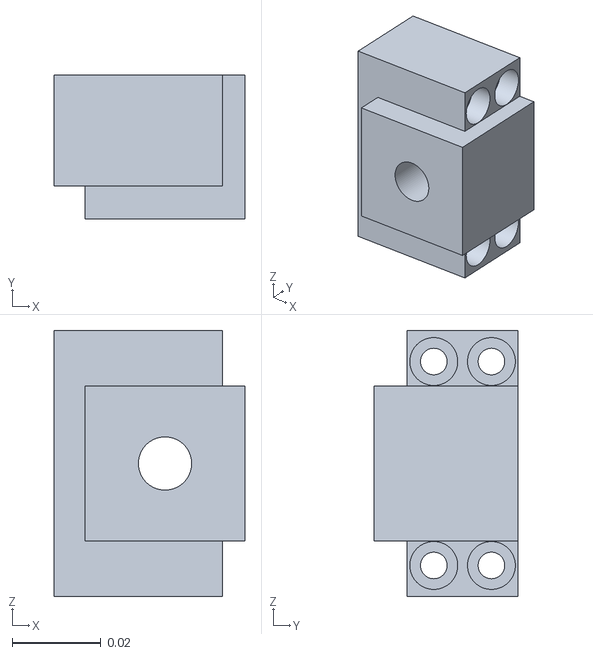
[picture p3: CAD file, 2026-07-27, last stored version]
cad/assets/part_1__25.stl
0.043 x 0.0325 x 0.06

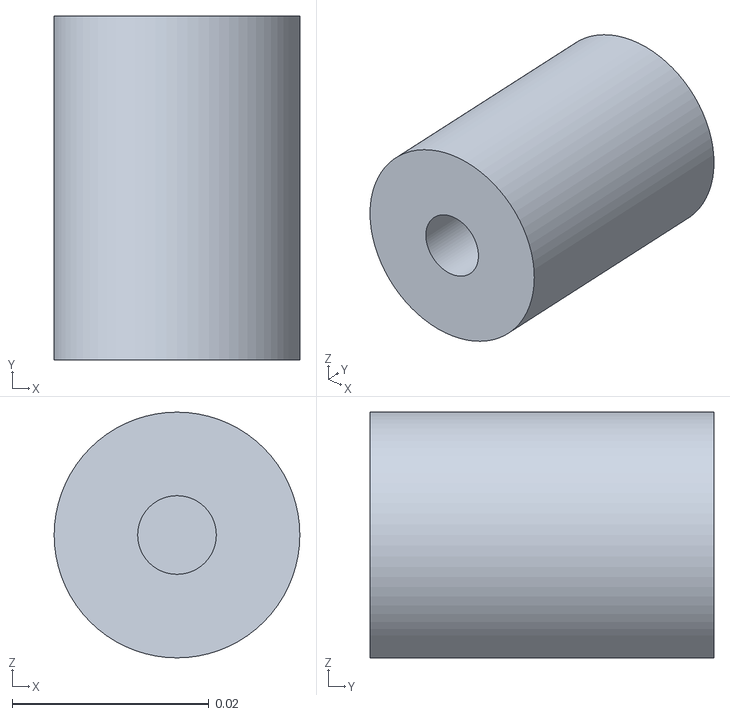
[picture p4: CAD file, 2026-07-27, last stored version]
cad/assets/part_1__43.stl
0.025 x 0.035 x 0.025

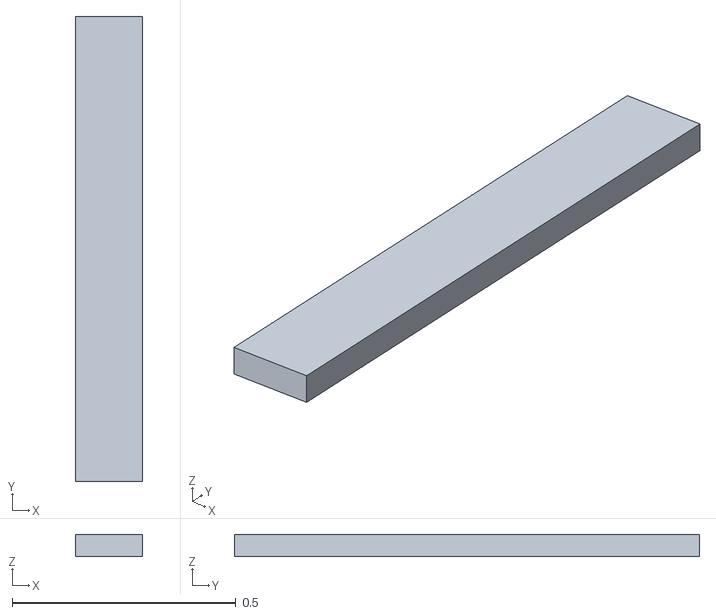
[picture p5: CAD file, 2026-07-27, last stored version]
cad/assets/part_107.stl
0.15 x 1.04 x 0.05

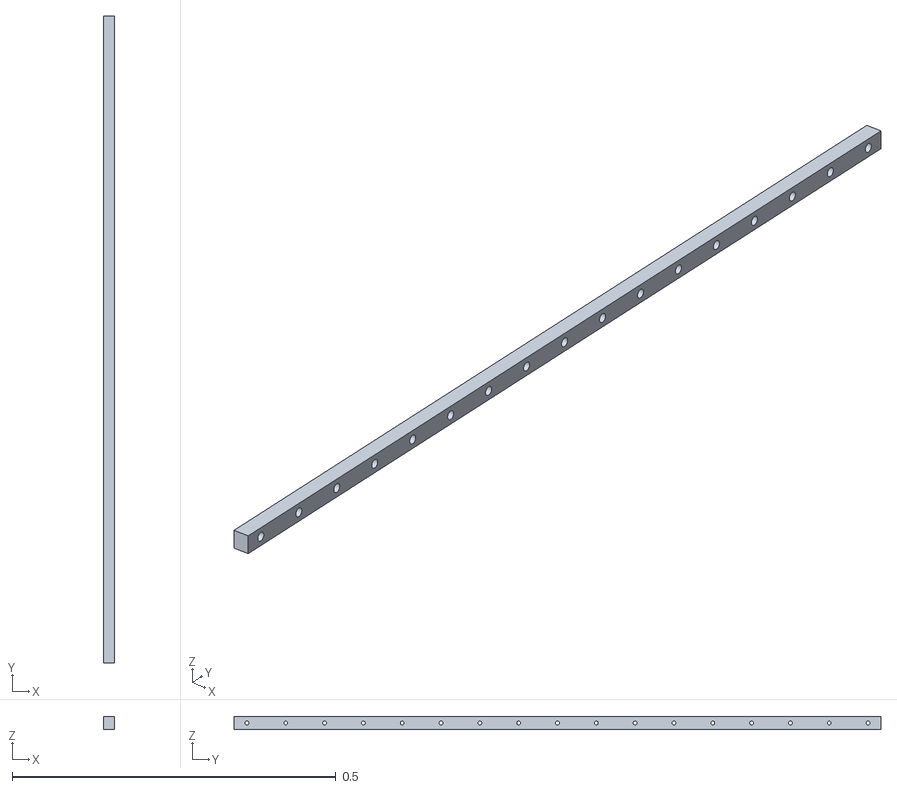
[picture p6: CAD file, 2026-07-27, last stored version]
cad/assets/part_1__45.stl
0.0175 x 1.00 x 0.02

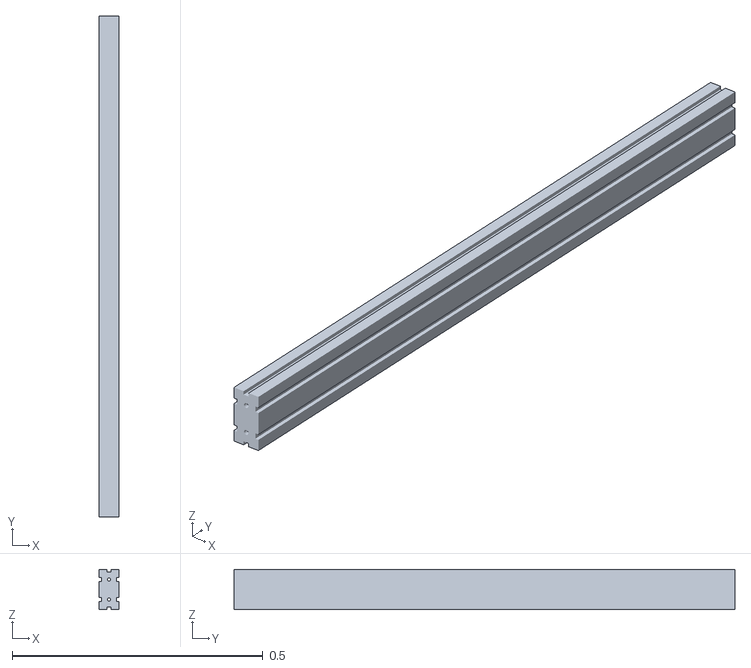
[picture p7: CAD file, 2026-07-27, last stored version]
cad/assets/part_1__30.stl
0.04 x 1.00 x 0.08

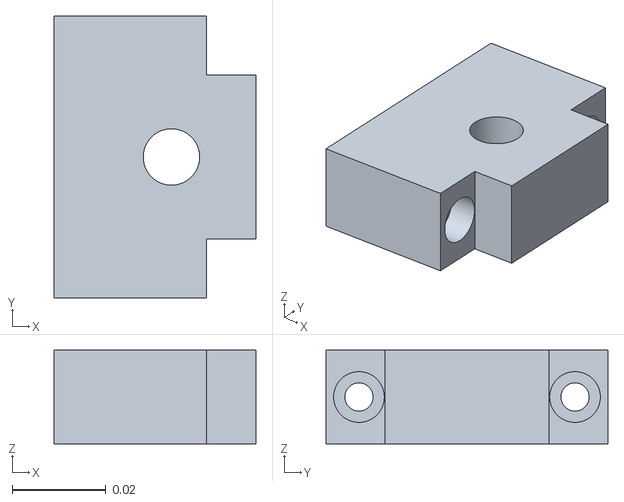
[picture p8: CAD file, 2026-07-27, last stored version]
cad/assets/part_1__17.stl
0.043 x 0.06 x 0.02

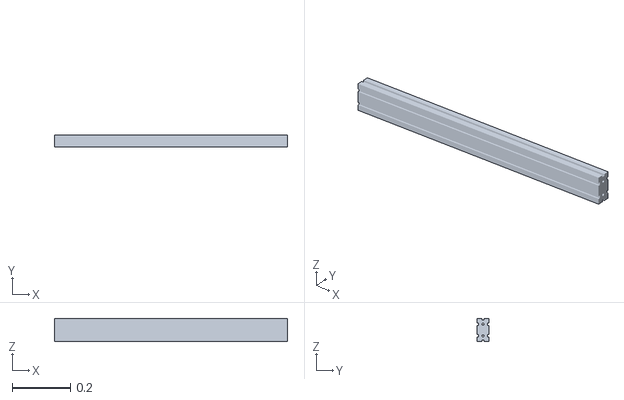
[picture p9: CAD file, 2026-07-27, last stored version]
cad/assets/part_1__50.stl
0.8 x 0.04 x 0.08

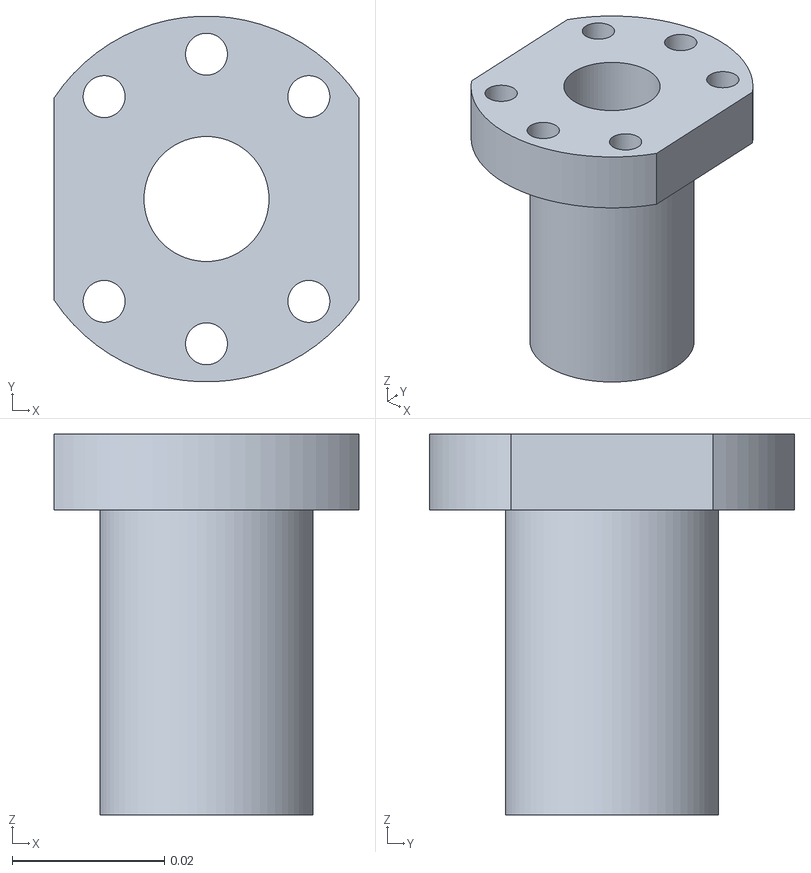
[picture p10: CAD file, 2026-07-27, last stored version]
cad/assets/part_2__6.stl
0.04 x 0.048 x 0.05

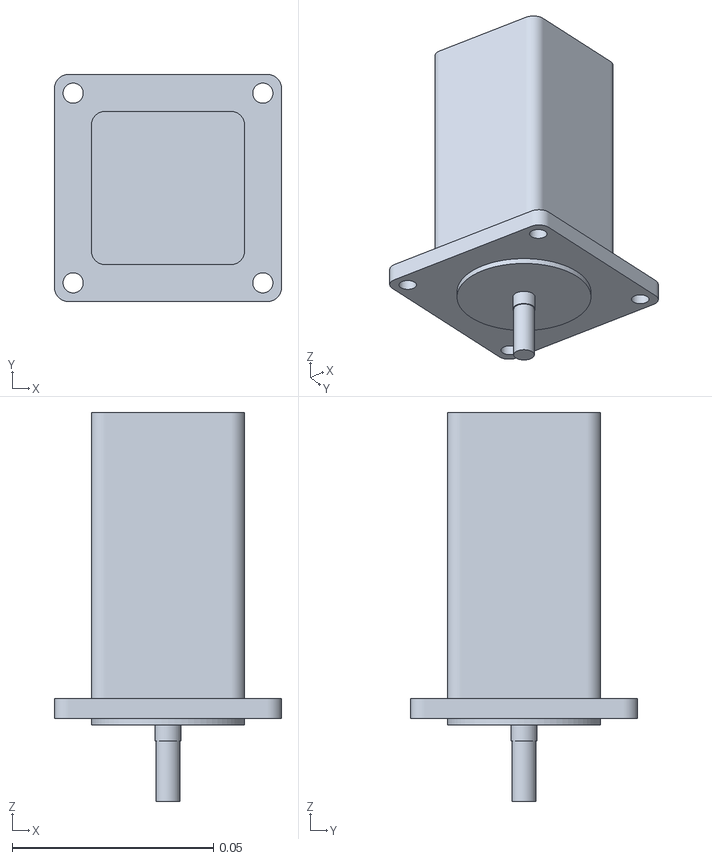
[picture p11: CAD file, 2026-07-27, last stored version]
cad/assets/part_1__24.stl
0.0564 x 0.0564 x 0.0966

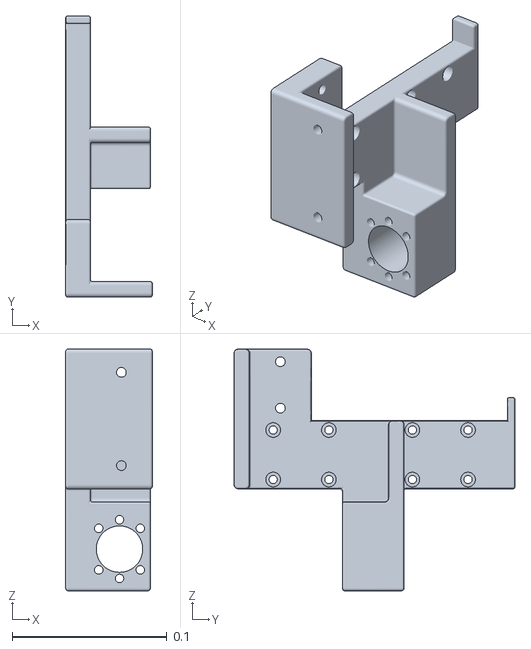
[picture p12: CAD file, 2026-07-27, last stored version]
cad/assets/part_24.stl
0.056 x 0.182 x 0.156

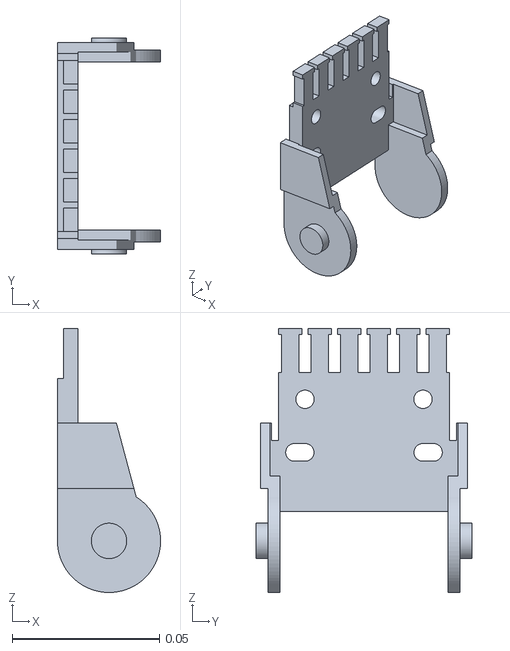
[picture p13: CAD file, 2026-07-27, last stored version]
cad/assets/part_3__7.stl
0.035 x 0.0732 x 0.0895

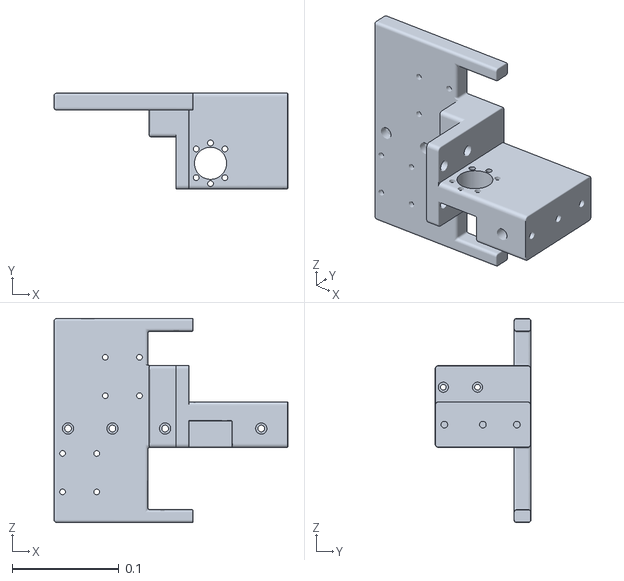
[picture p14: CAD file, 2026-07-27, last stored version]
cad/assets/part_16.stl
0.219 x 0.0897 x 0.191

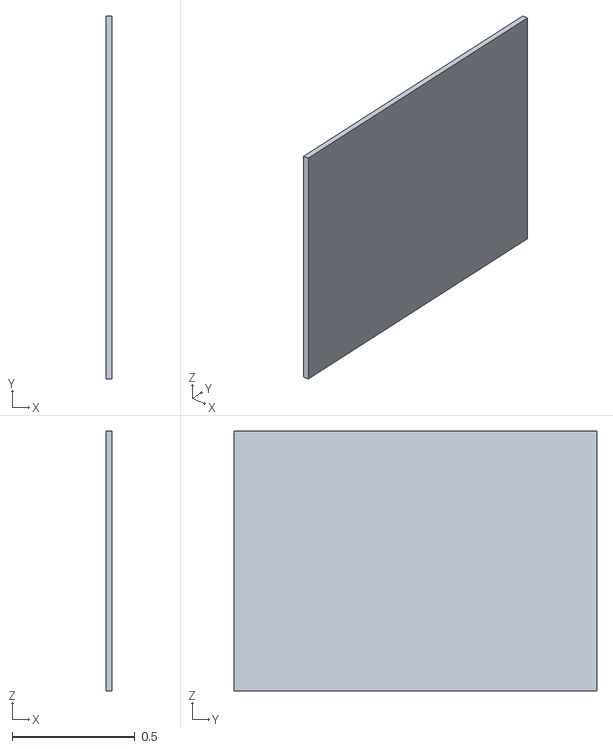
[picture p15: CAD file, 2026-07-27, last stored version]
cad/assets/part_105.stl
0.025 x 1.48 x 1.06

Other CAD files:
cad/assets/part_1__11.stl
cad/assets/part_7.stl
cad/assets/part_12__2.stl
cad/assets/part_1__49.stl
cad/assets/hg_c1030.stl
cad/assets/hg_c1030__2.stl
cad/assets/part_1.stl
cad/assets/part_10.stl
cad/assets/part_104.stl
cad/assets/part_106.stl
cad/assets/part_11.stl
cad/assets/part_12.stl
cad/assets/part_121.stl
cad/assets/part_14.stl
cad/assets/part_14__2.stl
cad/assets/part_17.stl
cad/assets/part_17__2.stl
cad/assets/part_18.stl
cad/assets/part_19.stl
cad/assets/part_1__10.stl
cad/assets/part_1__12.stl
cad/assets/part_1__13.stl
cad/assets/part_1__14.stl
cad/assets/part_1__15.stl
cad/assets/part_1__16.stl
cad/assets/part_1__18.stl
cad/assets/part_1__19.stl
cad/assets/part_1__2.stl
cad/assets/part_1__21.stl
cad/assets/part_1__22.stl
cad/assets/part_1__23.stl
cad/assets/part_1__26.stl
cad/assets/part_1__27.stl
cad/assets/part_1__28.stl
cad/assets/part_1__29.stl
cad/assets/part_1__3.stl
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

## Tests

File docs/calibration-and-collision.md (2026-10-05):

# Calibration and collision scripts

Routine operation uses the installed `openderm-*` commands documented in the root README. Utilities under `src/scripts/` create rig-specific calibration files and validate the collision envelope.

All utility arguments are required run-specific inputs: angles, modes, input files, and output locations. Persistent settings are loaded from [`config/scripts.json`](../config/scripts.json), resolved relative to the checkout regardless of the working directory. There are no CLI defaults or tuning overrides. Missing, unknown, or invalid settings fail before hardware connections or collision generation start.

Configure the file once for the rig:

- `calibration`: gantry/RX URLs, shared Pico connection, standoff, Z regulation, and ADC averaging. These settings apply to both capture and floor tare. Connection values in this file replace the scripts' former URL/port environment defaults; the control token still comes from `OPENDERM_CONTROL_TOKEN`.
- `rx_pivot_capture`: angle units (`degrees: false` means radians), initial jog size, display cadence, axis motion settings, and startup homing policy. Jog size can still be adjusted interactively with `[` and `]`.
- `floor_depth_tare`: startup homing policy, bounded search travel/time, settling and measurement counts, RX sweep motion settings, and debugging. `max_travel_mm` limits the calibration search from its starting position; controller travel limits remain enforced independently.
- `collision`: margin, measured RX backlash, and grid resolution. Worker count is selected automatically from available CPUs. Travel ranges come from `config/cad/frame_calibration.json`; keep Z resolution dense enough for the runtime guard's conservative lookup (the reference grid uses 30 points).

Motion settings belong to the controllers except for the explicit capture Y/Z speeds and floor-tare RX sweep speed in this file. All script settings require concrete values. The supplied homing settings are `false`, so axes must already be homed unless you change that policy. The former `--tolerance-mm` option was removed because the Pico Z adapter did not use it.

## Hardware calibration

Run these tools from `src/scripts/calibration/`.

- `rx_pivot_capture.py` records same-point poses across the RX scan range.
- `rx_pivot_fit.py` fits those poses into the RX rotation model used by `openderm-scan`.
- `floor_depth_tare.py` measures the bed rejection threshold.

From the repository root:

```bash
python src/scripts/calibration/rx_pivot_capture.py 0.95 \
    --record-file captures/rx_pivot_poses.jsonl
python src/scripts/calibration/rx_pivot_fit.py captures/rx_pivot_poses.jsonl \
    --out captures/rx_pivot_model.json
python src/scripts/calibration/floor_depth_tare.py point \
    --out captures/floor_depth.json
python src/scripts/calibration/floor_depth_tare.py sweep 0.35:1.5:6 \
    --out captures/floor_depth_sweep.json
```

Capture appends to the explicitly selected record file; fit and tare write to the explicitly selected output file. Floor tare's mode must be selected: `point` records the current tilt without moving RX, while `sweep LO:HI:N` samples N angles in radians and fits the RX dependence. Standoff comes from `calibration.target_mm` for both utilities.

These calibration files are physical measurements, not universal defaults. Recreate them after changes to the sensor mount or lever arm. Camera intrinsics must be calibrated independently as described in the root README.

## Collision tools

Run these tools from `src/scripts/collision/`.

- Install the offline collision stack with `pip install -e ".[collision]"`.
- `collision_model.py` evaluates CAD clearances with FCL.
- `build_collision_envelope.py` generates the runtime collision envelope from `config/cad/robot.urdf`.

```bash
python src/scripts/collision/build_collision_envelope.py sweep \
    --grid config/cad/collision_clearance.npz --out config/cad/collision_envelope.npz
python src/scripts/collision/build_collision_envelope.py derive \
    --grid config/cad/collision_clearance.npz --out config/cad/collision_envelope.npz
```

`sweep` writes the raw grid and derives the envelope. After changing margin or backlash in `config/scripts.json`, `derive` reads the selected grid and writes the selected envelope without repeating the sweep. Both paths are required and must be different files; use `.npz` filenames.

Run every calibration on an inert target and at reduced speed before a person enters the workspace. Treat a generated collision envelope as unvalidated until the physical machine has completed an independent engineering safety review.

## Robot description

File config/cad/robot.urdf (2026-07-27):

<?xml version="1.0" ?>
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
<robot name="cad">
  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
  <link name="hg_c1030">
    <inertial>
      <origin xyz="0 0 0" rpy="0 0 0"/>
      <mass value="1e-09"/>
      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
    </inertial>
    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
  </link>
  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
  <link name="part_1">
    <inertial>
      <origin xyz="0 0 0" rpy="0 0 0"/>
      <mass value="1e-09"/>
      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
    </inertial>
    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
  </link>
  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
  <link name="part_1_2">
    <inertial>
      <origin xyz="0 0 0" rpy="0 0 0"/>
      <mass value="1e-09"/>
      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
    </inertial>
    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
  </link>
  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
  <link name="part_1_3">
    <inertial>
      <origin xyz="0 0 0" rpy="0 0 0"/>
      <mass value="1e-09"/>
      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
    </inertial>
    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
  </link>
  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
  <link name="part_1_4">
    <inertial>
      <origin xyz="0 0 0" rpy="0 0 0"/>
      <mass value="1e-09"/>
      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
    </inertial>
    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
  </link>
  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
  <joint name="x" type="prismatic">
    <origin xyz="-0.1237 -0.02975 -0.48283" rpy="1.5708 -0 0"/>
    <parent link="part_1_3"/>
    <child link="part_1_4"/>
    <axis xyz="0 0 1"/>
    <limit effort="10" velocity="10" lower="-0.594238" upper="0.225262"/>
  </joint>
  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
  <joint name="y" type="prismatic">
    <origin xyz="-0.09775 -0.1 -0.05635" rpy="-1.5708 1.5708 0"/>
    <parent link="part_1_2"/>
    <child link="part_1_3"/>
    <axis xyz="0 0 1"/>
    <limit effort="10" velocity="10" lower="-0.37077" upper="0.30983"/>
  </joint>
  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
  <joint name="z" type="prismatic">
    <origin xyz="0.296088 0.065 -0.14804" rpy="-0 -1.5708 0"/>
    <parent link="part_1"/>
    <child link="part_1_2"/>
    <axis xyz="0 0 1"/>
    <limit effort="10" velocity="10" lower="-0.4065" upper="0"/>
  </joint>
  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
  <joint name="rx" type="revolute">
    <origin xyz="0.233537 0.177993 0.027636" rpy="-1.5708 -0 -0"/>
    <parent link="hg_c1030"/>
    <child link="part_1"/>
    <axis xyz="0 0 1"/>
    <limit effort="10" velocity="10" lower="-0.959931" upper="0.959931"/>
  </joint>
</robot>

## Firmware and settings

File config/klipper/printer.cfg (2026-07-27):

# Baseline Klipper configuration for the 1-DOF ballscrew gantry.
# Verify all Octopus Pro V1.1 pins against your exact board revision before powering hardware.

[include macros.cfg]

[mcu]
# Replace this placeholder with the result of: ls /dev/serial/by-id/*
serial: /dev/serial/by-id/<your-klipper-mcu-id>
restart_method: command

[printer]
kinematics: cartesian
max_velocity: 30
max_accel: 1000

[stepper_x]
# These pins are placeholders for a single Octopus Pro stepper socket wired to the CL57Y PUL/DIR inputs.
step_pin: PF13
dir_pin: PF12
enable_pin: PF14
microsteps: 16
rotation_distance: 5
endstop_pin: ^PG6
position_endstop: 0
position_min: 0
position_max: 800
homing_speed: 22
second_homing_speed: 5
homing_retract_dist: 5

[stepper_x1]
step_pin: PG0
dir_pin: PG1
enable_pin: PF15
microsteps: 16
rotation_distance: 5
endstop_pin: ^PG10

# Klipper's cartesian parser requires Y and Z stepper sections. These are
# inert required sections: no Y/Z motor driver or endstop is wired
# to the Octopus. OpenDerm sends only X commands to Klipper; the Pico exclusively
# controls Y and Z. Use HOME_X_SAFE or G28 X, never an unqualified G28.
[stepper_y]
step_pin: PF11
dir_pin: PG3
enable_pin: PG5
microsteps: 16
rotation_distance: 5
endstop_pin: ^PG12
position_endstop: 0
position_max: 665
homing_speed: 15
second_homing_speed: 5
homing_retract_dist: 5

[stepper_z]
step_pin: PG4
dir_pin: PC1
enable_pin: PA0
microsteps: 16
rotation_distance: 5
endstop_pin: ^PG14
position_endstop: 0
position_max: 392
homing_speed: 15
second_homing_speed: 5
homing_retract_dist: 5

[respond]

# [gcode_button x_home]
# pin: ^PG6
# press_gcode:
#   RESPOND MSG="PG6 pressed"

[gcode_button x_max_limit]
pin: ^PG9
press_gcode:
  M112

# [gcode_button x1_home]
# pin: ^PG10
# press_gcode:
#     RESPOND MSG="PG10 pressed"

[gcode_button x1_max_limit]
pin: ^PG11
press_gcode:
   M112

[display_status]

# [force_move]
# enable_force_move: True

[idle_timeout]
timeout: 3600

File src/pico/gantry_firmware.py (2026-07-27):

# gantry_firmware.py -- Multi-axis (Y + Z) motion server for the Raspberry Pi Pico.
# ruff: noqa: F821
#
# The rp2.asm_pio decorator injects assembler instructions such as pull(),
# mov(), and jmp() while compiling _step_prog; they are not Python globals.
#
# Per-axis PIO step generation (block mode) + an accel-limited velocity/position controller
# + a line-based USB-serial command protocol for low-latency Y/Z target streaming.
#
# AXES (both CL57Y, 640 steps/mm, NC limit switches, MF opto OFF = enabled):
#   Y: step GP2, dir GP3, MF GP4, home GP14, end GP10   (PIO0 SM0)   -- hardware-verified
#   Z: step GP6, dir GP7, MF GP8, home GP21, end GP17   (PIO1 SM4)   -- hardware-verified
#
# PROTOCOL (newline-terminated; replies OK/ERR; async EVT). Commands are addressed to an
# axis with an optional Y/Z token; commands without an axis token default to Y:
#   PING                          -> OK PONG
#   EN  [axis] <0|1>              -> enable/disable (free) that axis
#   HOME [axis] [fast] [slow]     -> two-stage home, then zero (blocks)
#   VMAX [axis] <mm_s>            -> set max velocity
#   ACC  [axis] <mm_s2>           -> set acceleration
#   MOVE [axis] <mm>              -> absolute target (position mode), returns immediately
#   MOVEM [C] <ax> <mm> [..]      -> multi-axis absolute target in ONE command (saves a
#                                    round trip when streaming Y+Z); leading C = cruise
#                                    (MOVEC). e.g. MOVEM Y 263.98 Z 309.97. All-or-nothing:
#                                    if any axis isn't homed / is past its soft limit, none move.
#   JOG  [axis] <mm_s>            -> continuous signed velocity until STOP/limit
#   STOP [axis]                   -> decelerate to a stop
#   POS? [axis]                   -> OK POS [axis] <mm> <homed> <moving>
#   SOFT [axis] <0|1>             -> enable/disable soft-limit enforcement
#   BENCH [axis] [period_us]      -> step-rate benchmark (motor freed; re-HOME after)
#   STATUS?                       -> OK STATUS y ... | z ...   (all axes)
#   BYE                           -> stop the server

import rp2
from machine import Pin
import sys
import uselect
import math
import time

# ---------------- PIO clock / timing (shared) ----------------
PIO_HZ = 1_000_000  # 1 cycle = 1 us
PIO_OVERHEAD = 7  # ~fixed cycles per pulse in the job loop
MIN_DELAY = 1
FIFO_DEPTH = 4
JOB_WORDS = 2  # words per (count-1, delay) job
IO_MS = 3  # serial/EVT servicing period (ms)
DEBOUNCE_MS = 4  # limit-switch debounce (ms): rejects stepper-driver EMI spikes on
# the high-impedance switch inputs (a real press holds; noise does not)
BLOCK_MS = 3  # motion planned in fixed time-slices
BLOCK_S = BLOCK_MS / 1000.0

VELOCITY = 0
POSITION = 1

# ---------------- per-axis config ----------------
# Y -- hardware-verified.
Y_STEP, Y_DIR, Y_MF, Y_HOME, Y_END, Y_SM = 2, 3, 4, 14, 10, 0
Y_STEPS_PER_MM = 640
Y_DIR_HOME = 1  # dir value that moves toward the home switch (y decreases)
Y_HOME_NC = True  # NC switches: idle LOW, pressed/open HIGH
Y_END_NC = True
Y_SOFT_MIN_MM, Y_SOFT_MAX_MM = 0.0, 665.0  # Physical-travel backstop.
# Self-collision is enforced separately by the host collision guard.
Y_VMAX_MM_S, Y_ACC_MM_S2, Y_VSTART_MM_S = 20.0, 1000.0, 1.0
Y_HOME_FAST_MM_S, Y_HOME_SLOW_MM_S = 20.0, 5.0
Y_HOME_BACKOFF_MM, Y_HOME_MAX_MM = 3.0, 670.0

# Z -- hardware-verified reference pinout, direction, and switch polarity.
Z_STEP, Z_DIR, Z_MF, Z_HOME, Z_END, Z_SM = 6, 7, 8, 21, 17, 4
Z_STEPS_PER_MM = 640  # Tune from the Z drive mechanics and verify measured travel.
Z_DIR_HOME = 1  # Direction value that moves toward the home switch.
Z_HOME_NC = True  # NC switches: idle LOW, pressed/open HIGH.
Z_END_NC = True
Z_SOFT_MIN_MM, Z_SOFT_MAX_MM = 0.0, 392.0  # physical travel backstop (app clamps tighter)
Z_VMAX_MM_S, Z_ACC_MM_S2, Z_VSTART_MM_S = 20.0, 1000.0, 1.0
Z_HOME_FAST_MM_S, Z_HOME_SLOW_MM_S = 20.0, 5.0
Z_HOME_BACKOFF_MM, Z_HOME_MAX_MM = 3.0, 400.0


# ---------------- PIO step-pulse generator (block mode) ----------------
# Each job = two TX-FIFO words: (count-1, delay). Emits `count` HIGH pulses (3 us) spaced
# `delay` cycles apart, then pulls the next job. Empty FIFO -> stalls with the pin LOW.
@rp2.asm_pio(set_init=rp2.PIO.OUT_LOW)
def _step_prog():
    pull(block)
    mov(y, osr)
    pull(block)
    mov(isr, osr)
    label("loop")
    mov(x, isr)
    set(pins, 1)[2]
    set(pins, 0)
    label("dly")
    jmp(x_dec, "dly")
    jmp(y_dec, "loop")


def _send(line):
    sys.stdout.write(line)
    sys.stdout.write("\n")


class Axis:
    def __init__(
        self,
        name,
        sm_id,
        step_pin,
        dir_pin,
        mf_pin,
        home_pin,
        end_pin,
        steps_per_mm,
        dir_home,
        home_nc,
        end_nc,
        soft_min_mm,
        soft_max_mm,
        vmax_mm_s,
        acc_mm_s2,
        vstart_mm_s,
        home_fast_mm_s,
        home_slow_mm_s,
        home_backoff_mm,
        home_max_mm,
    ):
        self.name = name
        self.steps_per_mm = steps_per_mm
        self.dir_home = dir_home
        self.dir_end = 1 - dir_home
        self.home_nc = home_nc
        self.end_nc = end_nc
        self.soft_min = int(soft_min_mm * steps_per_mm)
        self.soft_max = int(soft_max_mm * steps_per_mm)
        self.vstart = vstart_mm_s * steps_per_mm
        self.vmax = vmax_mm_s * steps_per_mm
        self.acc = acc_mm_s2 * steps_per_mm
        self.brake_steps = self.vmax * self.vmax / (2.0 * self.acc)
        self.home_fast_mm_s = home_fast_mm_s
        self.home_slow_mm_s = home_slow_mm_s
        self.home_backoff = int(home_backoff_mm * steps_per_mm)
        self.home_max = int(home_max_mm * steps_per_mm)
        self._step_pin = step_pin
        self._sm_id = sm_id
        self.dr = Pin(dir_pin, Pin.OUT, value=self.dir_end)
        self.mf = Pin(mf_pin, Pin.OUT, value=0)  # opto OFF = enabled
        self.home_sw = Pin(home_pin, Pin.IN, Pin.PULL_UP)
        self.end_sw = Pin(end_pin, Pin.IN, Pin.PULL_UP)
        self.sm = None
        self.pos = 0
        self.target = 0
        self.speed = 0.0
        self.cmd_vel = 0.0
        self.cur_dir = self.dir_end
        self.mode = VELOCITY
        self.enabled = True
        self.homed = False
        self.clamped = False
        self.soft = True
        self.cruise = False  # POSITION look-ahead: cruise THROUGH the target at vmax
        # (no decel-to-zero), for streamed waypoints. Set by MOVEC,
        # cleared by MOVE/JOG/STOP/HOME. Overshoot is still impossible
        # (n is clamped to the remaining distance); a target reached
        # with no fresh waypoint just hard-stops there.
        self.last_lim = (False, False)  # last reported (debounced) state, for EVT LIMIT
        self.lim = (False, False)  # debounced limit state used by motion/homing/EVT
        self._lim_cand = (False, False)  # candidate raw state awaiting the debounce window
        self._lim_t = 0

    def activate(self):
        # (Re)create the SM each run so the FIFO/shift state starts clean (an orphaned
        # half-job from a mid-pair Ctrl-C cannot carry into the next run).
        self.sm = rp2.StateMachine(
            self._sm_id, _step_prog, freq=PIO_HZ, set_base=Pin(self._step_pin, Pin.OUT)
        )
        self.sm.active(1)
        self.set_enabled(True)

    def deactivate(self):
        if self.sm is not None:
            self.sm.active(0)

    @staticmethod
    def _pressed(level, nc):
        return (level == 1) if nc else (level == 0)

    def limits(self):
        """Raw (un-debounced) limit read: (home_pressed, end_pressed)."""
        return (
            self._pressed(self.home_sw.value(), self.home_nc),
            self._pressed(self.end_sw.value(), self.end_nc),
        )

    def poll_limits(self):
        """Debounced limit state. A change is committed only once the raw read holds steady
        for DEBOUNCE_MS, which rejects stepper-driver EMI spikes on the switch inputs while a
        real (held) press still registers. Returns the debounced (home_pressed, end_pressed)."""
        raw = self.limits()
        now = time.ticks_ms()
        if raw != self._lim_cand:
            self._lim_cand = raw
            self._lim_t = now
        elif raw != self.lim and time.ticks_diff(now, self._lim_t) >= DEBOUNCE_MS:
            self.lim = raw
        return self.lim

    def pos_mm(self):
        return self.pos / self.steps_per_mm

    def moving(self):
        return abs(self.speed) >= self.vstart

    def set_enabled(self, on):
        self.enabled = bool(on)
        self.mf.value(0 if self.enabled else 1)  # opto OFF = enabled
        if not self.enabled:
            self.speed = 0.0
            self.cmd_vel = 0.0

    def recalc_brake(self):
        self.brake_steps = self.vmax * self.vmax / (2.0 * self.acc)

    def _set_dir_when_drained(self, new_dir):
        if new_dir == self.cur_dir:
            return True
        if self.sm.tx_fifo() != 0:
            return False
        self.cur_dir = new_dir
        self.dr.value(new_dir)
        time.sleep_us(20)  # DIR setup time
        return True

    def emit_block(self):
        """Plan one BLOCK_S time-slice and push it as a (count-1, delay) job. Returns True
        if a block was emitted, False if idle / waiting for the FIFO to drain."""
        DIR_HOME, DIR_END = self.dir_home, self.dir_end
        if self.mode == POSITION:
            d = self.target - self.pos
            if d == 0:
                cmd = 0.0
            else:
                ad = abs(d)
                if self.cruise or ad >= self.brake_steps:
                    # cruise: hold vmax THROUGH the waypoint (no decel envelope) so a
                    # streamed sequence flows continuously; the n<=rem clamp below still
                    # prevents overshoot, and a stale waypoint just hard-stops at target.
                    cmd = self.vmax if d > 0 else -self.vmax
                else:
                    v = math.sqrt(2.0 * self.acc * ad)
                    cmd = v if d > 0 else -v
        else:
            cmd = self.cmd_vel

        hp, ep = self.lim
        limited = False
        if cmd < 0 and hp:
            cmd = 0.0
            limited = True
        if cmd > 0 and ep:
            cmd = 0.0
            limited = True
        if self.soft and self.homed:
            if cmd < 0:
                rem = self.pos - self.soft_min
                if rem <= 0:
                    cmd = 0.0
                    limited = True
                elif rem < self.brake_steps:
                    vs = math.sqrt(2.0 * self.acc * rem)
                    if -cmd > vs:
                        cmd = -vs
            elif cmd > 0:
                rem = self.soft_max - self.pos
                if rem <= 0:
                    cmd = 0.0
                    limited = True
                elif rem < self.brake_steps:
                    vs = math.sqrt(2.0 * self.acc * rem)
                    if cmd > vs:
                        cmd = vs

        dv = self.acc * BLOCK_S
        if cmd > self.speed:
            self.speed = min(cmd, self.speed + dv)
        else:
            self.speed = max(cmd, self.speed - dv)

        if self.mode == POSITION and not self.cruise:
            d = self.target - self.pos
            ad = abs(d)
            if d != 0 and ad < self.brake_steps:
                vs = math.sqrt(2.0 * self.acc * ad)
                if abs(self.speed) > vs:
                    self.speed = vs if self.speed > 0 else -vs

        if abs(self.speed) < self.vstart:
            if cmd == 0.0:
                self.speed = 0.0
                if (
                    self.mode == POSITION
                    and self.target != self.pos
                    and limited
                    and not self.clamped
                ):
                    self.clamped = True
                    _send(
                        "EVT CLAMP %s pos=%.3f tgt=%.3f"
                        % (self.name, self.pos_mm(), self.target / self.steps_per_mm)
                    )
                return False
            new_dir = DIR_END if cmd > 0 else DIR_HOME
            if not self._set_dir_when_drained(new_dir):
                return False
            self.speed = self.vstart if cmd > 0 else -self.vstart

        want_dir = DIR_END if self.speed > 0 else DIR_HOME
        if not self._set_dir_when_drained(want_dir):
            return False

        spd = abs(self.speed)
        n = int(spd * BLOCK_S)
        if n < 1:
            n = 1
        if self.mode == POSITION:
            rem = abs(self.target - self.pos)
            if rem == 0:
                # A cruise (MOVEC) waypoint reached with no fresh target = stream underrun:
                # the axis is still at speed and hard-stops here (vmax->0 in one block), which
                # can skip steps and desync commanded vs actual. Emit ONCE (the next block's
                # speed is already 0, so the guard won't re-fire) so the host can detect it
                # and re-home if needed. A normal MOVE has decelerated to ~vstart by now, but
                # the self.cruise guard keeps it from ever tripping this.
                if self.cruise and abs(self.speed) >= self.vstart:
                    _send("EVT UNDERRUN %s pos=%.3f" % (self.name, self.pos_mm()))
                self.speed = 0.0
                return False
            if n > rem:
                n = rem
        if self.soft and self.homed:
            room = (
                (self.soft_max - self.pos)
                if self.cur_dir == DIR_END
                else (self.pos - self.soft_min)
            )
            if room <= 0:
                self.speed = 0.0
                return False
            if n > room:
                n = room
        delay = int(1_000_000.0 / spd) - PIO_OVERHEAD
        if delay < MIN_DELAY:
            delay = MIN_DELAY
        self.sm.put(n - 1)
        self.sm.put(delay)
        self.pos += n if self.cur_dir == DIR_END else -n
        return True

    def feed(self):
        if not self.enabled:
            return
        while self.sm.tx_fifo() <= FIFO_DEPTH - JOB_WORDS:
            if not self.emit_block():
                break

    # --- homing (blocking; abort_cb() lets the host cancel) ---
    def _home_run(
        self,
        direction,
        max_steps,
        period_us,
        abort_cb,
        until_home_pressed=False,
        until_home_released=False,
        n=8,
    ):
        while self.sm.tx_fifo() != 0:
            pass
        time.sleep_us(800)  # let the prev job finish before DIR flip
        while not self._set_dir_when_drained(direction):
            pass
        delay = max(MIN_DELAY, period_us - PIO_OVERHEAD)
        inc = n if direction == self.dir_end else -n
        emitted = 0
        i = 0
        while emitted < max_steps:
            if (i & 15) == 0 and abort_cb():
                _send("EVT ABORT %s host-stop" % self.name)
                return False
            i += 1
            hp, ep = self.poll_limits()
            if until_home_pressed and hp:
                return True
            if until_home_released and not hp:
                return True
            if ep:
                _send("EVT ABORT %s end-switch" % self.name)
                return False
            if direction == self.dir_home and hp and not until_home_pressed:
                _send("EVT ABORT %s home-switch" % self.name)
                return False
            while self.sm.tx_fifo() >= JOB_WORDS:
                pass
            self.sm.put(n - 1)
            self.sm.put(delay)
            self.pos += inc
            emitted += n
        return not (until_home_pressed or until_home_released)

    def do_home(self, abort_cb, fast_mm_s=None, slow_mm_s=None):
        if not self.enabled:
            return False
        # Park every OTHER axis before this blocking home: while do_home busy-waits, the
        # other axis isn't fed and its FIFO drains (it physically stops). Zeroing its speed
        # here makes it re-accelerate from rest afterwards instead of jumping back to a stale
        # vmax (a velocity discontinuity / missed-step jolt).
        for other in AXES:
            if other is not self:
                other.cmd_vel = 0.0
                other.speed = 0.0
                other.mode = VELOCITY
                other.target = other.pos
        fast_mm_s = self.home_fast_mm_s if fast_mm_s is None else fast_mm_s
        slow_mm_s = self.home_slow_mm_s if slow_mm_s is None else slow_mm_s
        self.homed = False
        self.clamped = False
        self.cruise = False
        self.speed = 0.0
        self.cmd_vel = 0.0
        self.mode = VELOCITY
        fast_us = int(1_000_000 / (fast_mm_s * self.steps_per_mm))
        slow_us = int(1_000_000 / (slow_mm_s * self.steps_per_mm))
        clear = self.home_backoff + 10 * self.steps_per_mm
        if self.lim[0]:
            if not self._home_run(self.dir_end, clear, slow_us, abort_cb, until_home_released=True):
                return False
            if not self._home_run(self.dir_end, self.home_backoff, slow_us, abort_cb):
                return False
        if not self._home_run(
            self.dir_home, self.home_max, fast_us, abort_cb, until_home_pressed=True, n=8
        ):
            return False
        if not self._home_run(self.dir_end, self.home_backoff, slow_us, abort_cb, n=8):
            return False
        if not self._home_run(
            self.dir_home,
            self.home_backoff + 2 * self.steps_per_mm,
            slow_us,
            abort_cb,
            until_home_pressed=True,
            n=1,
        ):
            return False
        while self.sm.tx_fifo() != 0:
            pass
        time.sleep_ms(5)
        self.pos = 0
        self.target = 0
        self.homed = True
        return True

    def bench(self, per):
        was = self.enabled
        self.set_enabled(False)
        total, nblk = 20000, 128
        delay = max(MIN_DELAY, per - PIO_OVERHEAD)
        done = 0
        t0 = time.ticks_us()
        while done < total:
            while self.sm.tx_fifo() > FIFO_DEPTH - JOB_WORDS:
                pass
            self.sm.put(nblk - 1)
            self.sm.put(delay)
            done += nblk
        while self.sm.tx_fifo() != 0:
            pass
        us = time.ticks_diff(time.ticks_us(), t0)
        self.set_enabled(was)
        return done, us


# ---------------- axes + shared state ----------------
Y = Axis(
    "y",
    Y_SM,
    Y_STEP,
    Y_DIR,
    Y_MF,
    Y_HOME,
    Y_END,
    Y_STEPS_PER_MM,
    Y_DIR_HOME,
    Y_HOME_NC,
    Y_END_NC,
    Y_SOFT_MIN_MM,
    Y_SOFT_MAX_MM,
    Y_VMAX_MM_S,
    Y_ACC_MM_S2,
    Y_VSTART_MM_S,
    Y_HOME_FAST_MM_S,
    Y_HOME_SLOW_MM_S,
    Y_HOME_BACKOFF_MM,
    Y_HOME_MAX_MM,
)
Z = Axis(
    "z",
    Z_SM,
    Z_STEP,
    Z_DIR,
    Z_MF,
    Z_HOME,
    Z_END,
    Z_STEPS_PER_MM,
    Z_DIR_HOME,
    Z_HOME_NC,
    Z_END_NC,
    Z_SOFT_MIN_MM,
    Z_SOFT_MAX_MM,
    Z_VMAX_MM_S,
    Z_ACC_MM_S2,
    Z_VSTART_MM_S,
    Z_HOME_FAST_MM_S,
    Z_HOME_SLOW_MM_S,
    Z_HOME_BACKOFF_MM,
    Z_HOME_MAX_MM,
)
AXES = (Y, Z)
BY_NAME = {"y": Y, "z": Z}

_running = True
_poll = uselect.poll()
_poll.register(sys.stdin, uselect.POLLIN)
_home_line = ""
_pending = []  # lines received during a blocking HOME; run() dispatches them after


def _is_abort(line, homing_name):
    """True if `line` is a stop aimed at the axis currently homing (or a global STOP/BYE)."""
    parts = line.split()
    if not parts:
        return False
    c = parts[0].upper()
    if c == "BYE":
        return True
    rest = parts[1:]
    if rest and rest[0].upper() in ("Y", "Z"):
        name = rest[0].lower()
        rest = rest[1:]
    else:
        name = "y"
    if c == "STOP":
        return name == homing_name
    if c == "EN":
        return name == homing_name and bool(rest) and rest[0] == "0"
    return False


def _abort_requested(homing_name):
    """Non-blocking: read any complete lines that arrived during a blocking HOME. Buffer them
    all in _pending (run() dispatches them afterwards -- nothing is dropped) and return True if
    one is a stop aimed at the homing axis (or a global STOP/BYE)."""
    global _home_line
    aborted = False
    while _poll.poll(0):
        ch = sys.stdin.read(1)
        if not ch:
            break
        if ch in ("\n", "\r"):
            ln = _home_line.strip()
            _home_line = ""
            if ln:
                _pending.append(ln)
                if _is_abort(ln, homing_name):
                    aborted = True
        else:
            _home_line += ch
            if len(_home_line) > 80:
                _home_line = ""
    return aborted


def _tag(explicit, name):
    return (name.upper() + " ") if explicit else ""
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

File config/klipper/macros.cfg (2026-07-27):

[gcode_macro HOME_X_SAFE]
description: Home the X axis only after clearing any previous emergency stop.
gcode:
  FIRMWARE_RESTART
  G28 X

[gcode_macro MOVE_X_MM]
description: Move X to an absolute position in millimeters, example: MOVE_X_MM X=125 F=1200
gcode:
  {% set target = params.X|float %}
  {% set feed = params.F|default(1200)|float %}
  G90
  G1 X{target} F{feed}

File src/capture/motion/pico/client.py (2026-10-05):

#!/usr/bin/env python3
"""Host-side client for the multi-axis Pico gantry firmware.

The Pico serves MULTIPLE axes (Y, Z) over ONE serial port, so the connection is shared:

  PicoLink   -- owns the serial connection + the line protocol (axis-agnostic cmd()).
  AxisClient -- a thin per-axis convenience built on a PicoLink (default Y), for interactive
                use. The contour/pivot scripts use the GantryServerClient-compatible adapter
                in capture.motion.pico.adapter (PicoAxisClient), which also shares a
                single PicoLink across Y and Z.

A pyserial URL is accepted as the port (e.g. socket://pi1-ip:8095) so the Pico can be bridged
over the network by ``openderm-pico-bridge``. Requires pyserial.

Quick demo:  python3 third_party/pico/gantry_client.py            # ping, home Y, then move Y
             python3 third_party/pico/gantry_client.py --axis z   # same on Z
"""

import argparse
import socket
import time

import serial  # pyserial

from ..security import control_token_from_env


class PicoClientError(RuntimeError):
    pass


class PicoLink:
    """Owns the serial connection to the Pico and the newline-framed request/reply protocol.
    Shared by every axis (the Pico multiplexes axes over one port)."""

    def __init__(self, port="/dev/ttyACM0", baud=115200, timeout=2.0, on_event=None):
        # serial_for_url accepts a device path OR a URL (socket://host:port, ...).
        # write_timeout is CRITICAL for the network bridge: if the bridge stalls or has a
        # stale client, the TCP send buffer fills and a plain blocking write() would hang
        # FOREVER. With write_timeout, a stuck write raises (translated to
        # PicoClientError in cmd())
        # so callers report "link stalled" instead of freezing.
        self.ser = serial.serial_for_url(
            port, baudrate=baud, timeout=timeout, write_timeout=min(timeout, 5.0)
        )
        # Disable Nagle on a bridged socket:// transport. The protocol is tiny
        # newline-framed request/reply lines -- exactly the Nagle + delayed-ACK
        # pathological case (~40ms stall per round trip; measured ~61ms before this).
        # No effect on a real serial port (no underlying socket). Pyserial's socket://
        # handler stores the socket as `_socket`. Pair with the bridge's TCP_NODELAY.
        _sock = getattr(self.ser, "_socket", None)
        if _sock is not None:
            try:
                _sock.setsockopt(socket.IPPROTO_TCP, socket.TCP_NODELAY, 1)
            except OSError:
                pass
        self._read_base = timeout
        self.events = []
        self.on_event = on_event
        # serial_for_url() OPENS the port/socket immediately, so any failure in the setup
        # below (notably the liveness check raising for a silent Pico or a REPL echo) must
        # release it -- otherwise the handle leaks (a lingering TCP connection over the
        # bridge). Close-and-re-raise on ANY failure, including KeyboardInterrupt.
        try:
            control_token = control_token_from_env()
            if _sock is not None and control_token is not None:
                self._authenticate_bridge(control_token, timeout)
            time.sleep(0.2)
            self.ser.reset_input_buffer()
            # A freshly-opened connection (especially socket:// over the bridge, or USB-CDC)
            # can drop the first byte and/or leave a partial line in the firmware's input
            # buffer. Flush with newlines and absorb a dropped byte with a throwaway PING, so
            # the first REAL command isn't corrupted (e.g. SOFT -> OFT).
            try:
                self.ser.write(b"\n\n")
                self.ser.flush()
                time.sleep(0.05)
                self.cmd("PING", timeout=1.5)
            except (PicoClientError, serial.SerialException):
                pass
            self.ser.reset_input_buffer()
            # Liveness check: the gantry firmware answers PING with "OK PONG". If the reply is
            # the command echoed back (the Pico is at the MicroPython REPL, not running the
            # server) or there is no reply, fail NOW with a clear message -- otherwise every
            # later command silently reads an echo and the protocol is meaningless.
            try:
                reply = self.cmd("PING", timeout=1.5)
            except PicoClientError as exc:
                raise PicoClientError(
                    "no PING reply from the Pico on %s (%s). Is the gantry firmware running? "
                    "The "
                    "Pico boots to the REPL unless main.py is the server." % (port, exc)
                )
            if not reply.startswith("OK"):
                raise PicoClientError(
                    "Pico answered PING with %r, not 'OK PONG' -- the REPL is echoing, not the "
                    "gantry firmware. Deploy it as main.py (mpremote fs cp "
                    "src/pico/gantry_firmware.py :main.py), reset the Pico, then restart the "
                    "bridge." % reply
                )
        except BaseException:
            self.close()
            raise

    def _authenticate_bridge(self, token, timeout):
        """Authenticate a socket:// connection before any Pico bytes are relayed."""
        previous_timeout = self.ser.timeout
        try:
            self.ser.timeout = min(max(0.1, timeout), 5.0)
            self.ser.write(("AUTH " + token + "\n").encode())
            self.ser.flush()
            reply = self.ser.readline().decode(errors="replace").strip()
        except serial.SerialException as exc:
            raise PicoClientError("Pico bridge authentication failed: %s" % exc)
        finally:
            self.ser.timeout = previous_timeout
        if reply != "OK AUTH":
            raise PicoClientError(
                "Pico bridge rejected OPENDERM_CONTROL_TOKEN (expected 'OK AUTH', got %r)." % reply
            )

    def _stash(self, ln):
        self.events.append(ln)
        if self.on_event:
            self.on_event(ln)

    def _readline(self, deadline):
        while True:
            remaining = deadline - time.monotonic()
            if remaining <= 0:
                raise PicoClientError("timeout waiting for reply")
            self.ser.timeout = max(0.05, min(self._read_base, remaining))
            try:
                raw = self.ser.readline()
            except serial.SerialException as exc:
                raise PicoClientError("read failed (link dropped?): %s" % exc)
            if not raw:
                continue
            ln = raw.decode(errors="replace").strip()
            if not ln:
                continue
            if ln.startswith("EVT"):
                self._stash(ln)
                continue
            return ln
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

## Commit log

2026-07-27 Initial public release
    [hg_c1030.stl, hg_c1030__2.stl, macros.cfg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]
2026-10-04 Remove cad assets
    [hg_c1030.stl, hg_c1030__2.stl, part_1.stl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]
2026-10-06 Colmap capture version, working except for tough SIFT detections on the arm edges
2026-10-15 Update sim-capture to use SIFT GPU, use more Laplacian threshold instead of fixed frames, and add 3D COLMAP head renderer
